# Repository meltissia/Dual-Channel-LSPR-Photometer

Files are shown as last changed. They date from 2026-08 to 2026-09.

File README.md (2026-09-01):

# Dual-Channel LSPR Photometer Platform

Компактна двоканальна фотометрична платформа для реєстрації та цифрової обробки сигналів фотодіодів при дослідженні локалізованого поверхневого плазмонного резонансу (LSPR).

Пристрій побудований на **ESP32-WROOM-32**, 24-бітному ΔΣ АЦП **ADS1220** та двоканальному трансимпедансному analog front-end на **AD8616**.

Поточна апаратна ревізія **Rev.1.0** є Proof of Concept та використовувалася для повного bring-up аналогового, цифрового та програмного вимірювального тракту.

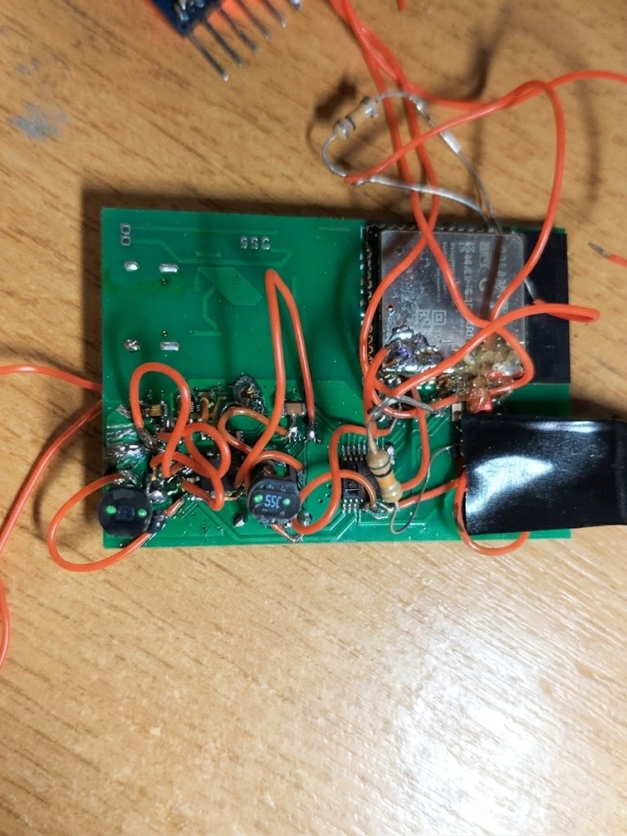
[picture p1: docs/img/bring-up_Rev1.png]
Rev.1 hardware prototype


---

## Hardware Overview

| Вузол | Специфікація |
|---|---|
| **MCU** | ESP32-WROOM-32 |
| **ADC** | ADS1220, 24-bit Delta-Sigma (Internal 2.048 V ref, 20 SPS, single-shot) |
| **Analog Front-End** | Dual AD8616 TIA (`Rf = 5.1 MΩ`, `Cf = 10 pF`), photovoltaic mode |
| **Bias** | `VSHIFT ≈ 1.42 V` relative to GNDA (measured on Rev.1.0) |
| **Sensors** | 2 × Hamamatsu S1087 Silicon Photodiodes |
| **Light Source** | Measurement LED switched via ESP32 GPIO27 |
| **Power** | BQ24074 charger + TPS63031 3.3 V buck-boost (shared digital/analog rail) |
| **PCB** | Custom 2-layer PCB, Rev.1.0 |
| **Status** | **Rev.1.0 PoC verified** — bring-up завершено; сформовано ТЗ на Rev.1.1 |

ADS1220 конфігурується у диференціальному режимі:
- **CH1:** `AIN0 − AIN1` (AIN1 підтягнуто до `VSHIFT`)
- **CH2:** `AIN2 − AIN3` (AIN3 підтягнуто до `VSHIFT`)

Зсув `VSHIFT ≈ 1.42 V` задає робочу common-mode точку для коректного оцифрування двополярного сигналу при однополярному живленні 3.3 В.

---

## System Architecture

```mermaid
flowchart LR
    subgraph OPTICAL ["Optical Front-End"]
        LED["Measurement LED<br/>(GPIO27)"]
        PD1["Hamamatsu S1087<br/>CH1"]
        PD2["Hamamatsu S1087<br/>CH2"]
    end

    subgraph AFE ["Analog Front-End"]
        TIA1["AD8616 TIA CH1<br/>Rf = 5.1 MΩ, Cf = 10 pF"]
        TIA2["AD8616 TIA CH2<br/>Rf = 5.1 MΩ, Cf = 10 pF"]
        VSHIFT["VSHIFT ≈ 1.42 V"]
    end

    subgraph ADC ["Acquisition"]
        ADS["ADS1220 (24-bit ΔΣ)<br/>Internal Ref 2.048 V | 20 SPS"]
    end

    subgraph MCU ["ESP32 Firmware Pipeline"]
        PIPE["• Sample averaging<br/>• Dark correction<br/>• Moving average (N=8)<br/>• Code → µV conversion<br/>• CH1/CH2 ratio"]
        UART["UART0 / CSV Output"]
    end

    LED -.-> PD1
    LED -.-> PD2

    PD1 --> TIA1
    PD2 --> TIA2

    VSHIFT -.-> TIA1
    VSHIFT -.-> TIA2

    TIA1 --> ADS
    TIA2 --> ADS

    ADS -- "SPI + DRDY" --> PIPE
    PIPE --> UART
```

---

## Firmware Overview

Прошивка реалізована мовою C під **ESP-IDF v6.0.2** для target `esp32`.

- **`ads1220`** — низькорівневий драйвер: конфігурація регістрів (`WREG`/`RREG`), контроль `DRDY`, таймінги передачі та читання 24-бітних вибірок.
- **`photometer`** — вимірювальний шар: мультиплексування каналів, віднімання темного струму (dark correction), усереднення, рухоме середнє ($N=8$) та розрахунок коефіцієнта каналів.
- **`photometer_output`** — пакетування та потоковий вивід даних у UART.
- **`main`** — секвенсер калібрування, керування оптичним джерелом та запуск циклу вимірювань.

---

## Quick Start

### Build & Flash

```bash
# Встановлення цільового чіпа та збірка
idf.py set-target esp32
idf.py build

# Прошивка та монітор (Windows: COMx, Linux/macOS: /dev/ttyUSBx)
idf.py -p COM7 flash monitor
```

*Примітка:* Розпіновка SPI та системних інтерфейсів зафіксована у коді Rev.1.0; деталі наведено у [Hardware Architecture & Pinout](docs/hardware.md).

---

## Data Output

Вимірювання транслюються через `UART0` у CSV-подібному форматі:

```text
DATA,40004171,26,1043353,1031889,11464,2798.828,11595,2830.811,204278,682426,-478148,-116735.352,-473754,-115662.598,-0.023976,-0.024475,1,1,0,0
```

Кожен рядок фіксує сирі коди обох каналів, значення темного зміщення, скориговані сигнали в $\mu\text{V}$, результат фільтрації, обчислене співвідношення та статус-прапорці saturation/validity.

Повний лог першого запуску:[**rev1_ads1220_.bringup_log.csv**](docs/logs/rev1_ads1220_.bringup_log.csv)

Структура полів та опис даних: [**Data Format & Bring-up Logs**](docs/logs/README.md)

> Дані першого запуску демонструють стабільну роботу цифрового SPI-тракту після усунення апаратних збоїв шини і не є метрологічно каліброваними.

---

## Limitations & Rev.1.1 Requirements

На ревізії Rev.1.0 зафіксовано апаратні обмеження, що увійшли до плану модернізації:

1. **Шум живлення:** Спільна шина 3.3 В від імпульсного перетворювача TPS63031 безпосередньо впливає на аналоговий тракт. Для Rev.1.1 закладено виділений ultra-low-noise LDO.
2. **Топологія AFE:** Відсутність виділеного guard ring навколо високоомного кола фотодіодів ($R_f = 5.1\,\text{M}\Omega$).
3. **Debug & Programming:** Відсутність розведеного окремого роз'єму для UART/EN/BOOT на платі.
4. **Метрологія:** Довготривалий дрейф, SNR, лінійність та повторюваність вимірювань перенесені на стендове тестування ревізії Rev.1.1.

---

## Documentation

- **Hardware:** [Hardware Architecture & Pinout](docs/hardware.md) · [PCB Design & Manufacturing Files](docs/hardware/) · [Hardware Errata](docs/ERRATA.md)
- **Firmware:** [Firmware Implementation & Notes](docs/firmware.md) · [Firmware Errata](docs/FIRMWARE_ERRATA.md)
- **Experimental Data:** [Data Format & Bring-up Logs](docs/logs/README.md)

---

## Legacy

Архітектура приладу розвиває концепцію двоканального LSPR-фотометра на базі **ATtiny2313(A)** та **ADS1242** (Assembly), реалізуючи аналогічний диференціальний оптичний принцип на сучасному 32-бітному ядрі ESP32.

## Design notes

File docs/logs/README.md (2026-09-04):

# UART Bring-up Logs

Референсний набір даних: [`rev1_ads1220_.bringup_log.csv`](rev1_ads1220_bringup_log.csv).

Цей набір даних збережено як підтвердження роботи цифрового acquisition pipeline Rev.1.0 після стабілізації SPI-інтерфейсу. Він містить двоканальне зчитування ADC, dark correction, перерахунок ADC-коду, moving-average processing, розрахунок співвідношення каналів та структурований UART output.

На стабільних ділянках логу відсутні раніше зафіксовані структуровані пошкодження SPI-даних, зсуви байтів та великі стрибки до некоректних ADC-кодів.

Зафіксовані фізичні значення сигналів не є метрологічно валідованими та не повинні інтерпретуватися як характеристика точності фотометра, noise floor, чутливості або довготривалої стабільності.

---

## Схема CSV Output

```text
record_type, timestamp_us, measurement_number,
ch1_raw, ch1_dark, ch1_corrected, ch1_uv, ch1_filtered, ch1_filtered_uv,
ch2_raw, ch2_dark, ch2_corrected, ch2_uv, ch2_filtered, ch2_filtered_uv,
ratio, filtered_ratio, ratio_valid, filtered_ratio_valid, ch1_saturated, ch2_saturated
```

### Приклад рядка

```text
DATA,40004171,26,1043353,1031889,11464,2798.828,11595,2830.811,204278,682426,-478148,-116735.352,-473754,-115662.598,-0.023976,-0.024475,1,1,0,0
```

> **Примітка:** Значення є даними bring-up та не являють собою абсолютну метрологічну калібровку.

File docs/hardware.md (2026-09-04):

# Апаратна архітектура та Errata (Rev.1.0)

## Аналоговий Front-End та Pinout

- **TIA:** AD8616 dual op-amp (`Rf = 5.1 MΩ`, `Cf = 10 pF`), photovoltaic mode.

- **Bias:** `VSHIFT ≈ 1.42 V` відносно GNDA для псевдодиференціального двополярного розмаху сигналу при однополярному живленні 3.3 V.

- **Сенсори:** 2 × фотодіоди Hamamatsu S1087.

- **Живлення:** BQ24074 charger + TPS63031 buck-boost зі спільною цифровою та аналоговою шиною живлення.

### Pin Mapping

| Периферія | Сигнал | ESP32 GPIO | Напрямок |
|---|---|---:|---|
| ADS1220 | CS | GPIO5 | Output |
| ADS1220 | DRDY | GPIO16 | Input |
| ADS1220 | SCLK | GPIO18 | Output |
| ADS1220 | DOUT | GPIO19 | Input |
| ADS1220 | DIN | GPIO23 | Output |
| Control | LED Trigger | GPIO27 | Output |
| Debug | UART0 TX / RX | GPIO1 / GPIO3 | — |

---

## Відомі проблеми та вимоги до Rev.1.1

- **Шина живлення:** Аналоговий front-end та ADC у Rev.1.0 живляться безпосередньо від спільної шини 3.3 V, сформованої TPS63031, без окремого low-noise post-regulation stage. Через це switching ripple та цифрові завади шини живлення потенційно можуть проникати у прецизійний аналоговий тракт.  
  *Rev.1.1:* Додати окреме малошумне живлення аналогового домену із застосуванням LDO або відповідного post-regulation / filtering stage з достатнім запасом напруги.

- **Guard Ring:** У Rev.1.0 guard structure була прив'язана до `GNDA` замість потенціалу `VSHIFT`, відносно якого працює високоімпедансний вузол TIA.  
  *Rev.1.1:* Перерозвести guard навколо високоімпедансних вузлів фотодіода/TIA та прив'язати його до `VSHIFT`, враховуючи паразитну ємність під час PCB layout.

- **Debug:** У Rev.1.0 не було передбачено окремого UART programming/debug header або JTAG access header.

- **Метрологія:** Довготривалий аналоговий дрейф, SNR та оптична лінійність мають бути валідовані на Rev.1.1.

## Рендери PCB Layout

<figure>
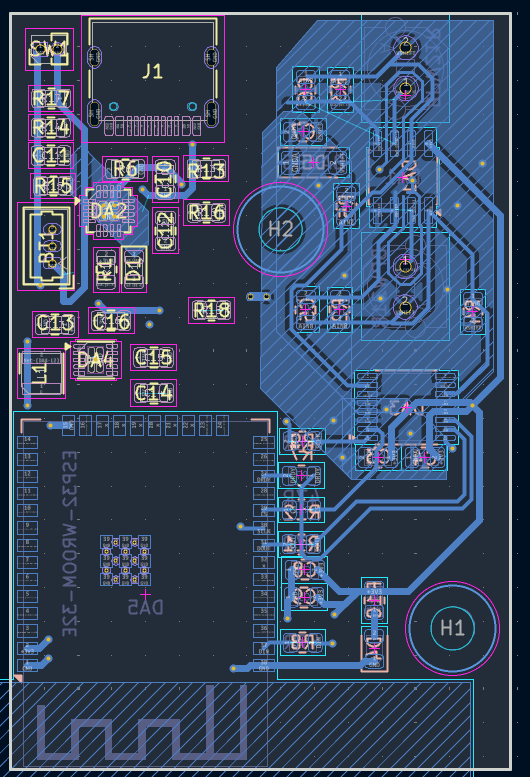
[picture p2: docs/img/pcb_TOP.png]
PCB Top Layer
  
  <figcaption align="center"><em>Рисунок 1 — Трасування верхнього шару (Top Layer): аналоговий тракт TIA, АЦП та обв'язка ESP32</em></figcaption>
</figure>

<figure>
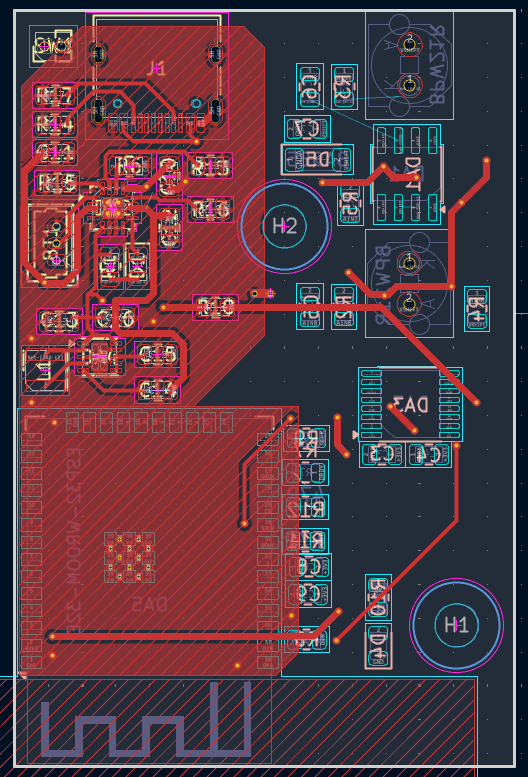
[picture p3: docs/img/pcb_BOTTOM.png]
PCB Bottom Layer
  
  <figcaption align="center"><em>Рисунок 2 — Трасування нижнього шару (Bottom Layer): суцільний полігон землі (GND plane) та силові ланцюги</em></figcaption>
</figure>

<figure>
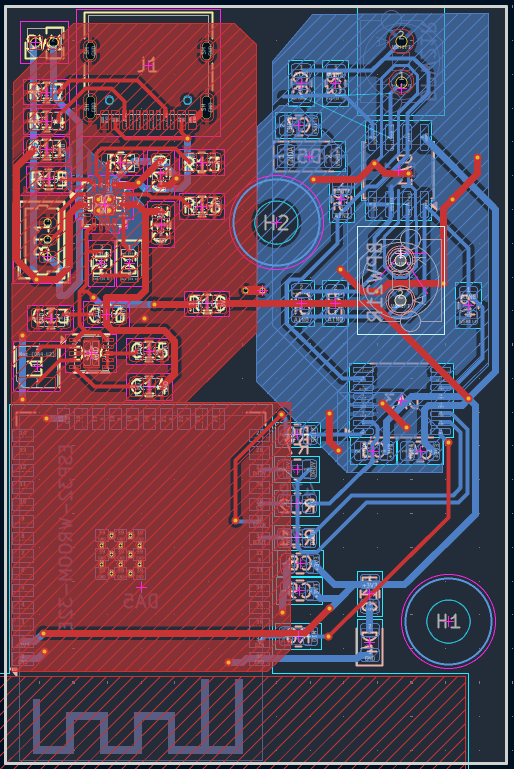
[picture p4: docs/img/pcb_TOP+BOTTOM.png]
PCB Top and Bottom Layers
  
  <figcaption align="center"><em>Рисунок 3 — Комбінований вигляд шарів (Top + Bottom): взаємне розташування трас і перехідних отворів</em></figcaption>
</figure>

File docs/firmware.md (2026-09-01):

# Реалізація прошивки та нотатки Bring-up

Зібрано з використанням **ESP-IDF v6.0.2** для target `esp32`.

## Структура модулів

- `ads1220.c / .h`: Низькорівневий драйвер, конфігурація регістрів через `WREG` / `RREG` із read-back перевіркою, обробка timeout для `DRDY`, запуск перетворень та перерахунок сирого ADC-коду у µV.

- `photometer.c / .h`: Двоканальне мультиплексоване зчитування, калібрування та корекція dark offset, boxcar moving average (`N = 8`), перевірка saturation та розрахунок співвідношення каналів.

- `photometer_output.c / .h`: Формування структурованого CSV-потоку через UART із timestamp та status flags.

- `main.c`: Керування апаратним bring-up та безперервним циклом збору даних.

## Нотатки Bring-up та Workaround

- Під час bring-up Rev.1.0 апаратний SPI-зв'язок з ADS1220 залишався нестабільним навіть при знижених тактових частотах. Тому драйвер було переведено на GPIO bit-bang SPI з явним програмним керуванням таймінгами `CS`, `SCLK`, `DIN` та `DOUT`.

- Для надійного доступу до регістрів та читання 24-бітних результатів перетворення знадобилися консервативні часові інтервали між змінами станів цифрових ліній.

- Перед читанням результату перетворення стан `DRDY` опитується з timeout, що запобігає необмеженому блокуванню та читанню даних до завершення ADC conversion.

- На Rev.1.0 додатково знадобилася повторна валідація `RDATA`, оскільки окремі 24-бітні читання могли залишатися пошкодженими навіть при коректному стані `DRDY`.

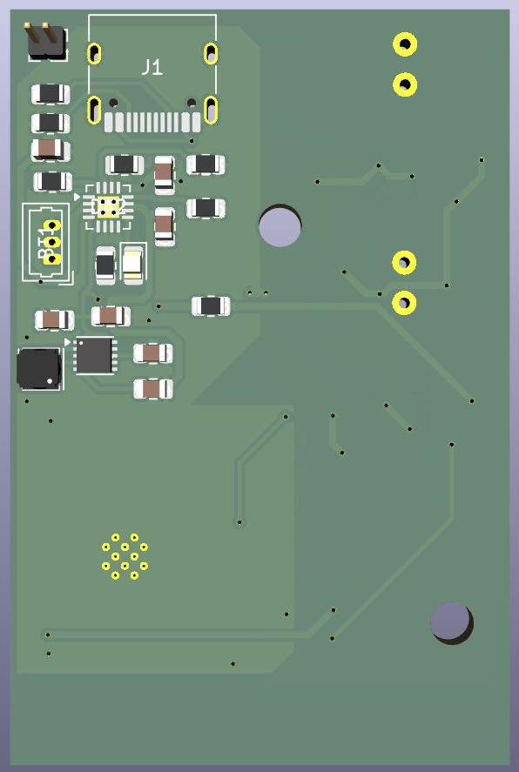
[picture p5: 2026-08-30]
docs/img/pcb_3D_BOTTOM.png

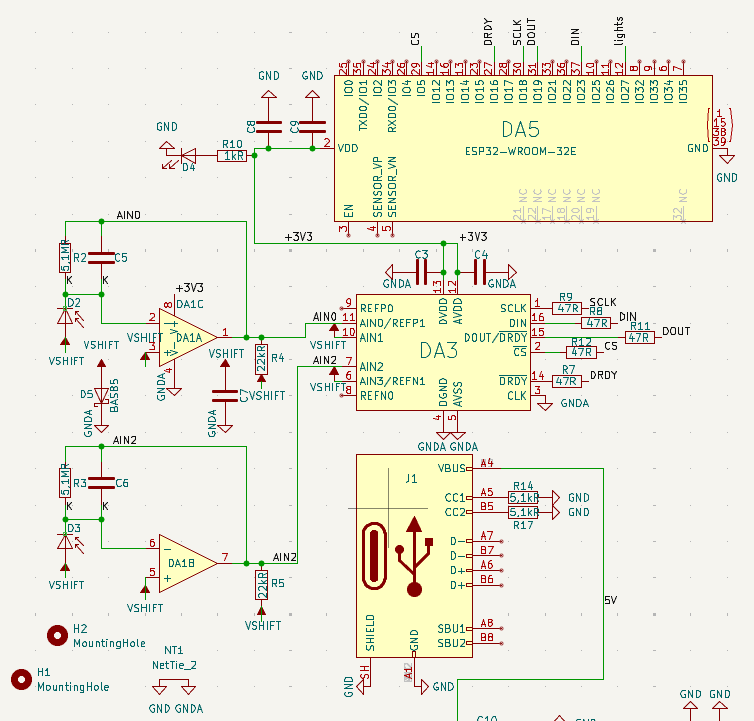
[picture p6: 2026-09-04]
docs/img/scheme_ANALOG.png

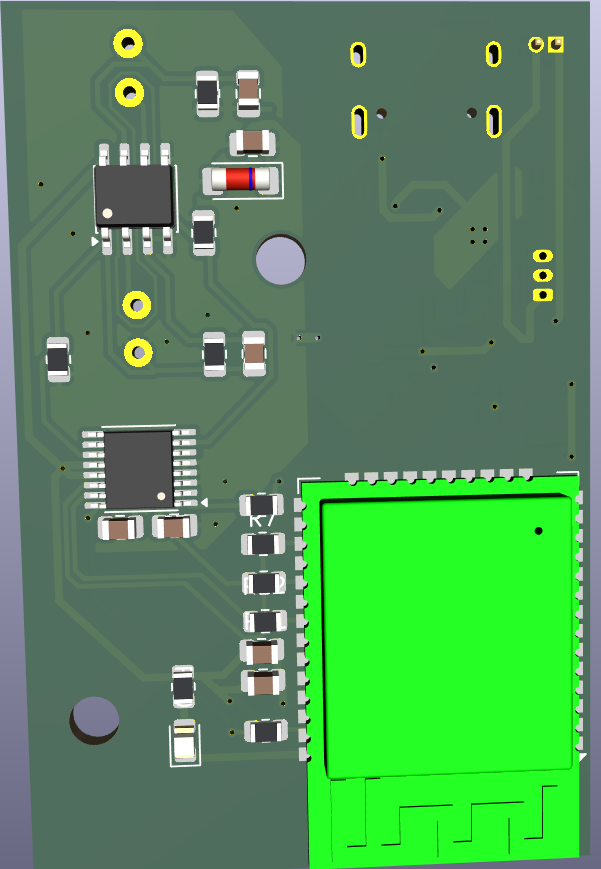
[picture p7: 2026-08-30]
docs/img/pcb_3D_TOP.png

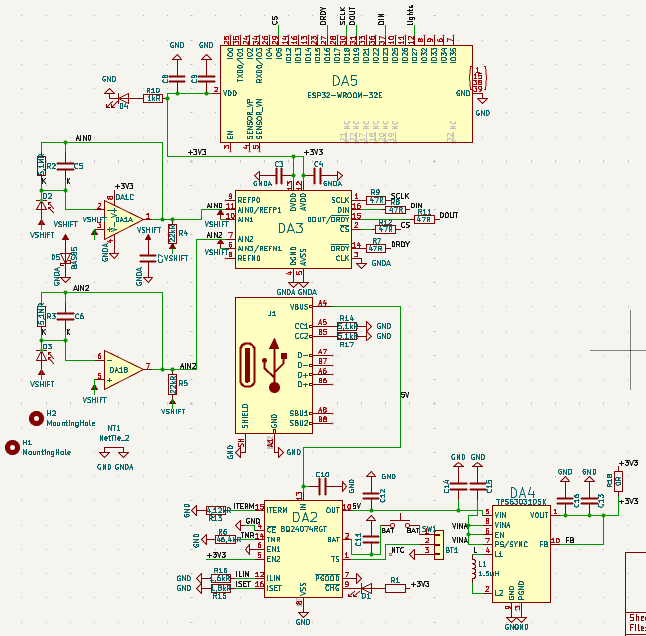
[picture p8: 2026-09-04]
docs/img/scheme_ALL.png

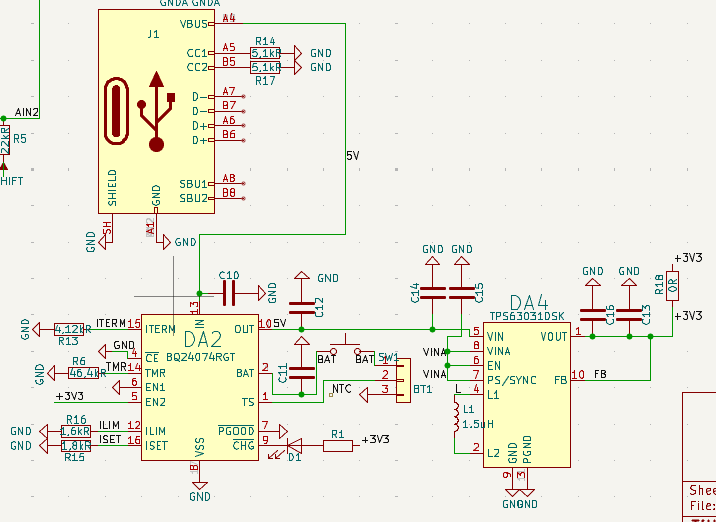
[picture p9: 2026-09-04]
docs/img/scheme.POWER.png

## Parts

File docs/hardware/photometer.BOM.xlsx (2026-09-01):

Reference | Qty | Value | DNP | Exclude from BOM | Exclude from Board | Footprint | Datasheet
BT1 | 1 | Akyga LP603450 PCM+NTC |  |  |  | Connector_Molex:Molex_PicoBlade_53047-0310_1x03_P1.25mm_Vertical
C3,C4,C8,C15 | 3 | 100nF |  |  |  | Capacitor_SMD:C_0805_2012Metric
C5,C6 | 2 | 10nF |  |  |  | Capacitor_SMD:C_0805_2012Metric
C7 | 1 | 220nF |  |  |  | Capacitor_SMD:C_0805_2012Metric
C9,C10,C13,C14,C16 | 5 | 10mcF |  |  |  | Capacitor_SMD:C_0805_2012Metric
C11,C12 | 2 | 4,7mcF |  |  |  | Capacitor_SMD:C_0805_2012Metric
D1 | 1 | LED Red, 0805 |  |  |  | LED_SMD:LED_0805_2012Metric
D2,D3 | 2 | BPW21R |  |  |  | Diode_THT:Hamamatsu_S1087_THT2
D4 | 1 | LED Green, 0805 |  |  |  | LED_SMD:LED_0805_2012Metric
D5 | 1 | BAS85 |  |  |  | Diode_SMD:D_MiniMELF
DA1 | 1 | AD8616ARZ |  |  |  | Package_SO:SOIC-8_3.9x4.9mm_P1.27mm
DA2 | 1 | BQ24074RGT |  |  |  | Package_DFN_QFN:VQFN-16-1EP_3x3mm_P0.5mm_EP1.6x1.6mm | http://www.ti.com/lit/ds/symlink/bq24074.pdf
DA3 | 1 | ADS1220xPW |  |  |  | Package_SO:TSSOP-16_4.4x5mm_P0.65mm | http://www.ti.com/lit/ds/symlink/ads1220.pdf
DA4 | 1 | TPS63031DSK |  |  |  | Package_SON:WSON-10-1EP_2.5x2.5mm_P0.5mm_EP1.2x2mm | http://www.ti.com/lit/ds/symlink/tps63031.pdf
DA5 | 1 | ESP32-WROOM-32E |  |  |  | RF_Module:ESP32-WROOM-32E | https://www.espressif.com/sites/default/files/documentation/esp32-wroom-32e_esp32-wroom-32ue_datasheet_en.pdf
J1 | 1 | USB_C_Receptacle_USB2.0_16P |  |  |  | Connector_USB:USB_C_Receptacle_HRO_TYPE-C-31-M-12 | https://www.usb.org/sites/default/files/documents/usb_type-c.zip
L1 | 1 | 1.5uH |  |  |  | Inductor_SMD_Wurth:L_Wurth_WE-LQSH-3012
R1,R10 | 2 | 1kR |  |  |  | Resistor_SMD:R_0805_2012Metric
R2,R3 | 2 | 5,1MR |  |  |  | Resistor_SMD:R_0805_2012Metric
R4,R5 | 2 | 22kR |  |  |  | Resistor_SMD:R_0805_2012Metric
R6 | 1 | 620kR |  |  |  | Resistor_SMD:R_0805_2012Metric
R7,R8,R9,R11,R12 | 5 | 47R |  |  |  | Resistor_SMD:R_0805_2012Metric
R13 | 1 | 4.3kR |  |  |  | Resistor_SMD:R_0805_2012Metric
R14,R17 | 2 | 5,1kR |  |  |  | Resistor_SMD:R_0805_2012Metric
R15 | 1 | 1,8kR |  |  |  | Resistor_SMD:R_0805_2012Metric
R16 | 1 | 1,6kR |  |  |  | Resistor_SMD:R_0805_2012Metric
R18 | 1 | 0R |  |  |  | Resistor_SMD:R_0805_2012Metric

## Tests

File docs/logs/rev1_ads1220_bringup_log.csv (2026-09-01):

record_type | timestamp_us | measurement_number | ch1_raw | ch1_dark | ch1_corrected | ch1_uv | ch1_filtered | ch1_filtered_uv | ch2_raw | ch2_dark | ch2_corrected | ch2_uv | ch2_filtered | ch2_filtered_uv | ratio | filtered_ratio | ratio_valid | filtered_ratio_valid | ch1_saturated | ch2_saturated
DATA | 1504235 | 1 | 962262 | 911858 | 50404 | 12305.664 | 50404 | 12305.664 | 313635 | 297193 | 16442 | 4014.160 | 16442 | 4014.160 | 3.065564 | 3.065564 | 1 | 1 | 0 | 0
DATA | 3044171 | 2 | 1011614 | 994121 | 17493 | 4270.752 | 33948 | 8288.086 | 313538 | 319199 | -5661 | -1382.080 | 5390 | 1315.918 | -3.090090 | 6.298330 | 1 | 1 | 0 | 0
DATA | 4584171 | 3 | 1022165 | 1015368 | 6797 | 1659.424 | 24898 | 6078.613 | 312594 | 319781 | -7187 | -1754.639 | 1198 | 292.480 | -0.945735 | 20.782972 | 1 | 1 | 0 | 0
DATA | 6124171 | 4 | 1027233 | 1020924 | 6309 | 1540.283 | 20250 | 4943.848 | 313350 | 317090 | -3740 | -913.086 | -36 | -8.789 | -1.686898 | -562.500000 | 1 | 1 | 0 | 0
DATA | 7664171 | 5 | 1029784 | 1025422 | 4362 | 1064.941 | 17073 | 4168.213 | 329980 | 317011 | 12969 | 3166.260 | 2564 | 625.977 | 0.336341 | 6.658736 | 1 | 1 | 0 | 0
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

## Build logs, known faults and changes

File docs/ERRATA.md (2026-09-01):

# Hardware Errata & Bring-up Log (Rev.1.0)

Документація апаратних проблем ревізії Rev.1.0, тимчасових доробок Bring-up та вимог до редизайну принципової схеми й топології друкованої плати Rev.1.1.

---

## 1. Апаратна частина (Hardware Errata & Fixes)

### Аналоговий тракт (TIA, Guard Ring & Bias)

- **Помилка топології TIA та фотодіодного вузла у принциповій схемі:**
  - *Проблема:* Аналоговий вузол Rev.1.0 був спроєктований некоректно на рівні принципової схеми. Вихід ОУ/вхід АЦП був помилково пов'язаний з `VSHIFT`, а підключення фотодіода та ланцюга зворотного зв'язку не відповідали правильній топології TIA.
  - *Root cause:* Помилка на етапі розробки принципової схеми Rev.1.0. Некоректна електрична топологія була перенесена в PCB layout без виявлення помилки до виготовлення плати.
  - *Rev.1 Fix:* Неправильні з'єднання фізично розірвані перерізанням доріжок і видаленням зайвих ділянок міді. Необхідні з'єднання TIA та фотодіодного вузла відновлено навісним монтажем і перемичками МГТФ. Ланцюг зворотного зв'язку (`R∥C`) залишено між виходом та інвертуючим входом ОУ; `VSHIFT` заведено на неінвертуючий вхід та анод фотодіода.
  - *Rev.1.1:* Повністю виправити принципову схему TIA і фотодіодного вузла, після чого заново виконати трасування аналогової частини. Перед переходом до PCB провести окрему перевірку netlist, полярності фотодіода та топології зворотного зв'язку.

- **Розрив полігону/траси VSHIFT:**
  - *Проблема:* Мережа `VSHIFT` виявилася фізично розірваною на дві незв'язані частини.
  - *Rev.1 Fix:* З'єднано перемичкою МГТФ з наскрізним продзвонюванням.
  - *Rev.1.1:* Відновити цілісність мережі `VSHIFT` та перевірити connectivity перед генерацією Gerber.

- **Топологія Guard Ring:**
  - *Проблема:* Охоронний провідник був підключений до `GNDA`, тоді як високоімпедансний вузол TIA працює поблизу потенціалу `VSHIFT`. Різниця потенціалів між сигнальним вузлом і guard-провідником збільшує вплив поверхневих струмів витоку через PCB.
  - *Rev.1.1:* Перерозвести guard-провідник навколо високоімпедансного вузла та підключити його до потенціалу `VSHIFT`. Використання суцільної захисної заливки під вузлом оцінювати окремо з урахуванням додаткової паразитної ємності.

#### Схема перекройки аналогового вузла TIA та Guard Ring:

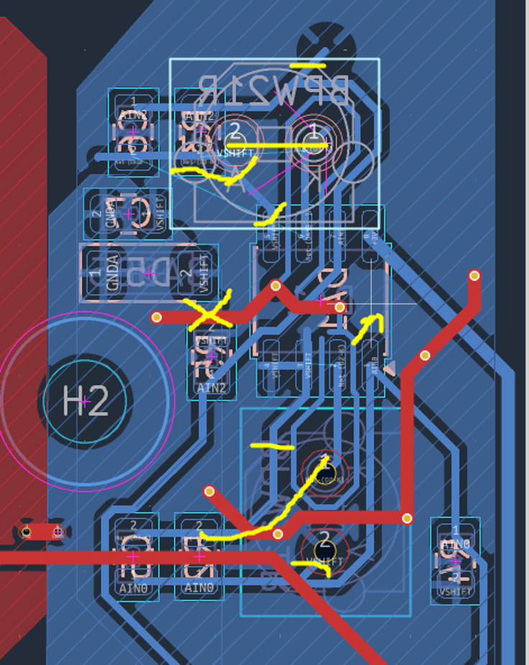
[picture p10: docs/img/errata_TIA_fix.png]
Схема виправлень вузла TIA


---

### Трасування АЦП, Зазори та Компонування

- **Недостатні технологічні зазори навколо ADS1220 (TSSOP-16):**
  - *Проблема:* Траси `DIN`, `DOUT`, `SCLK`, `DRDY` та `3V3` розведені занадто близько до виводів ADS1220, що ускладнює ручний монтаж, діагностику та локальний rework і підвищує ризик утворення паяльних містків та механічного пошкодження виводів.
  - *Rev.1.1:*
    - Збільшити clearance навколо ADS1220.
    - Спростити доступ до цифрових сигнальних ліній та, за можливості, передбачити test points для діагностики.
    - Фізично рознести цифрові SPI-лінії (`SCLK`, `DIN`, `DOUT`, `DRDY`) та чутливі аналогові входи ADS1220.
    - Уникати тривалого паралельного трасування цифрових і аналогових ліній.
    - Мінімізувати площу високочутливих аналогових вузлів.

- **Тісне компонування компонентів:**
  - *Проблема:* Резистори 47 Ом змонтовані впритул до модуля ESP32; роз'єм Molex акумулятора перекриває доступ до BQ24074.
  - *Rev.1.1:* Збільшити габарити плати орієнтовно в 1.5 раза для нормального доступу до вимірювальних вузлів, діагностики та ручного монтажу.

- **Помилка підключення R6:**
  - *Проблема:* Відсутній зв'язок одного з падів R6 із землею.
  - *Rev.1 Fix:* З'єднання з GND відновлено перемичкою.
  - *Rev.1.1:* Додати штатне via або пряме з'єднання з GND.

- **Помилка підключення C14:**
  - *Проблема:* До GND-паду C14 через термобар'єр було помилково підведено `5V`, що створювало пряме КЗ `5V ↔ GND`.
  - *Rev.1 Fix:* Хибну трасу `5V` відсічено.
  - *Rev.1.1:* Прибрати помилкову доріжку та повторно перевірити net connectivity вузла.

---

### Відсутність окремого малошумного живлення аналогового тракту

- **Проблема:** У Rev.1.0 аналоговий front-end та ADC живляться безпосередньо від системної шини `3.3 V`, сформованої імпульсним buck-boost перетворювачем TPS63031. Окремий low-noise post-regulation stage для прецизійного аналогового тракту не передбачений.

- **Наслідок:** Switching ripple та високочастотні завади системної шини потенційно можуть проникати у TIA, ADC та bias/reference nodes і погіршувати noise floor вимірювального тракту.

- **Rev.1.1:** Передбачити окреме малошумне живлення аналогового домену. Розглянути low-noise LDO з достатнім dropout/headroom або окремий post-regulation/filtering stage. Остаточну топологію та напругу аналогової шини визначити після розрахунку power budget, PSRR та допустимих діапазонів живлення AFE/ADC.

---

### Цифровий вузол та інтерфейс програмування

- **Інтерфейс прошивки та Reset/Boot-ланцюги ESP32:**
  - *Проблема:* Відсутність контактних майданчиків для `EN`, `GPIO0`, `TX0`, `RX0` ускладнила прошивання, перехід у Bootloader та діагностику плати. Під час bring-up довелося встановлювати зовнішні pull-up резистори навісним монтажем.
  - *Rev.1.1:*
    - Додати штатний UART/debug-роз'єм (`GND`, `TXD`, `RXD`, `EN`, `GPIO0`).
    - Встановити зовнішні pull-up/RC-елементи для `EN` і `GPIO0` відповідно до рекомендованої схеми ESP32-WROOM та обраної схеми auto-reset.

---

### Оптичне компонування та паразитна засвітка

- **Паразитний вплив статусного LED на вимірювальний тракт:**
  - *Проблема:* Червоний статусний LED розташований поблизу фотодіодів Hamamatsu S1087. Спектральний діапазон S1087 охоплює червону область, тому випромінювання індикатора може безпосередньо реєструватися вимірювальними каналами як паразитний оптичний сигнал.
  - *Додатковий фактор:* Локальний нагрів LED і прилеглої області PCB потенційно може створювати температурний дрейф фотодіодів та аналогового тракту.
  - *Rev.1 Fix:* LED екранується непрозорим матеріалом та, за можливості, вимикається під час критичних вимірювань.
  - *Rev.1.1:*
    - Передбачити механічне світлоблокування між індикаторними LED, фотодіодами та оптичним каналом для запобігання прямій і відбитій паразитній засвітці.
    - Збільшити оптичну та теплову розв'язку між індикаторними LED та фотодіодами.
    - Передбачити програмне вимкнення індикаторних LED на час вимірювального циклу.
    - Остаточне розташування LED визначити після експериментальної перевірки паразитної засвітки та температурного впливу.
    - Експериментально визначити необхідну затримку між вимкненням LED та початком прецизійного вимірювання.

---

## 2. Програмні воркараунди (Firmware Workarounds)

*Тимчасові модифікації коду, внесені під час bring-up Rev.1.0:*

- **Програмний Pull-up для сигнальних ліній:**
  - Конфігурація внутрішніх підтяжок `GPIO_PULLUP` в ESP-IDF використовувалася для компенсації відсутності зовнішніх резисторів на окремих цифрових лініях Rev.1.0.

- **Додаткові затримки під час ініціалізації ADS1220:**
  - Під час діагностики Rev.1.0 використовувалися збільшені програмні затримки перед доступом до SPI-регістрів ADS1220.
  - Конкретний апаратний механізм, який вимагав цих затримок, не встановлений.
  - Не вважати ці затримки постійним апаратним workaround до повторної перевірки їх необхідності після виготовлення Rev.1.1.

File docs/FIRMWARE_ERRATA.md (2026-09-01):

# Firmware Errata & Bring-up Notes (Rev.1.0)

Документація проблем програмного забезпечення, виявлених під час bring-up апаратної ревізії Rev.1.0, тимчасових firmware workaround та вимог до повторної перевірки після переходу на Rev.1.1.

---

## 1. Інтерфейс ADS1220 та SPI

### Нестабільна робота ADS1220 через апаратний SPI ESP32

- **Проблема:** Під час bring-up не вдалося отримати стабільний обмін з ADS1220 через апаратний SPI-контролер ESP32. Зниження частоти SPI, включно приблизно до 100 кГц, не усунуло нестабільність.
- **Прояв:** Періодичні помилки читання/запису регістрів ADS1220 та некоректні результати перетворення.
- **Root cause:** Остаточно не встановлений. Під час bring-up одночасно існували апаратні дефекти та нестабільність фізичних сигнальних ліній Rev.1.0, тому неможливо однозначно віднести проблему до SPI-периферії ESP32 або PCB.
- **Rev.1 Workaround:** Апаратний SPI замінено програмною реалізацією SPI через GPIO (bit-bang), з повним ручним керуванням `CS`, `SCLK`, `DIN` та читанням `DOUT`.
- **Rev.1.1:** Після усунення апаратних дефектів PCB повторно перевірити роботу штатного hardware SPI. Bit-bang не вважати обов'язковою архітектурою наступної ревізії без повторної валідації.

---

### Недостатні часові інтервали у початковій реалізації bit-bang SPI

- **Проблема:** Початкова реалізація програмного SPI використовувала затримки близько `10 µs` між змінами станів GPIO. За таких таймінгів інтерфейс періодично повертав пошкоджені дані.
- **Прояв:** Під час `RDATA` спостерігалися структуровані помилкові 24-бітні значення, великі стрибки коду та невідповідність між повторними читаннями однієї конверсії.
- **Rev.1 Workaround:** Затримки всередині передачі одного біта збільшено. Стабільна робота підтверджена при `50 µs`, після чого перевірено та залишено `30 µs`.
- **Rev.1.1:** Повторно визначити необхідні SPI timing після виправлення PCB. Значення `30 µs` розглядати як консервативний workaround Rev.1.0, а не як вимогу ADS1220.

---

### Чутливість до моменту вибірки DOUT відносно SCLK

- **Проблема:** Під час діагностики перевірялася альтернативна вибірка `DOUT` при високому рівні `SCLK`.
- **Прояв:** Зміна моменту вибірки призводила до негайної нестабільності `RREG` та неправильного читання регістрів.
- **Rev.1 Fix:** У робочій реалізації стан `DOUT` зчитується після спаду `SCLK`.
- **Rev.1.1:** Не змінювати фазу вибірки без повторної перевірки відповідно до timing diagram ADS1220 та вимірювання реальних фронтів сигналів.

---

### Відсутність достатньої перевірки конфігурації ADS1220 після запису регістрів

- **Проблема:** Одного виконання `WREG` недостатньо для підтвердження успішної конфігурації АЦП при нестабільному цифровому інтерфейсі.
- **Прояв:** Запис регістра міг завершитися без програмної помилки, але подальше читання показувало інше значення.
- **Rev.1 Fix:** Після конфігурації виконується `RREG` кожного конфігураційного регістра та порівняння з очікуваним значенням. При mismatch ініціалізація завершується помилкою.
- **Rev.1.1:** Зберегти read-back verification як механізм діагностики та контролю цілісності конфігурації.

---

### Необмежене очікування DRDY

- **Проблема:** Очікування завершення перетворення ADS1220 не повинно блокувати firmware необмежений час у випадку втрати `DRDY`, помилки SPI або несправності АЦП.
- **Rev.1 Fix:** Після `START/SYNC` реалізовано очікування готовності `DRDY` з програмним timeout.
- **Результат:** При відсутності готовності АЦП функція завершується контрольованою помилкою замість зависання вимірювального циклу.
- **Rev.1.1:** Зберегти timeout та обробку помилок як штатну частину драйвера.

---

### Недостатня надійність одиночного RDATA на Rev.1.0

- **Проблема:** Під час bring-up одиночна транзакція `RDATA` іноді повертала пошкоджений 24-бітний результат навіть після переходу `DRDY` у стан готовності.
- **Діагностика:** Повторне читання тієї самої конверсії показало, що перше значення могло відрізнятися, тоді як наступні читання повертали однаковий код.
- **Rev.1 Workaround:** Реалізовано до декількох незалежних транзакцій `RDATA`. Результат приймається лише після отримання двох послідовних повністю однакових 24-бітних значень.
- **Помилка:** Якщо стабільна пара значень не отримана за встановлену кількість спроб, повертається `ESP_ERR_INVALID_RESPONSE`.
- **Rev.1.1:** Після виправлення апаратного SPI-тракту перевірити необхідність цього workaround. За стабільного інтерфейсу перейти до штатного одиночного читання конверсії або залишити повторне читання лише як діагностичний механізм.

---

### Недетерміноване керування межами SPI-транзакцій у початковій реалізації

- **Проблема:** Під час раннього bring-up стан `SCLK` та межі окремих SPI-транзакцій не забезпечували достатньо передбачуваної поведінки протягом повного циклу запису/читання ADS1220.
- **Rev.1 Workaround:** У bit-bang реалізації програмне забезпечення явно формує кожну транзакцію:
  - `CS = LOW`;
  - передача команди;
  - передача або читання необхідних байтів;
  - `CS = HIGH`.
- **Додатково:** Рівень `SCLK` формується виключно програмно під час передачі кожного біта.
- **Rev.1.1:** При поверненні до hardware SPI повторно перевірити polarity, phase, idle state `SCLK` та поведінку `CS` між окремими командами ADS1220.

---

## 2. Діагностика та обробка помилок

### Некоректна діагностика стану CS у режимі output-only

- **Проблема:** Під час діагностики використовувалося програмне читання GPIO `CS`, однак пін був сконфігурований лише як вихід, що робило таку перевірку недостатньо надійною для діагностичних цілей.
- **Rev.1 Fix:** `CS` тимчасово переведено в режим `GPIO_MODE_INPUT_OUTPUT`, що дозволило контролювати фактичний логічний стан GPIO програмно.
- **Rev.1.1:** Якщо read-back `CS` не використовується у штатній firmware, повернути пін до мінімально необхідної конфігурації; діагностичний режим залишити опціональним.

---

### Надмірний діагностичний printf у часово-критичних циклах

- **Проблема:** Велика кількість `printf()` під час SPI stress-test та RDATA-діагностики істотно збільшувала навантаження на UART та scheduler.
- **Прояв:** Спотворений консольний вивід, значні затримки та у окремих тестових конфігураціях watchdog/reset.
- **Rev.1 Fix:** Детальний byte-level logging прибрано з робочого драйвера; у штатному вимірювальному циклі залишено лише необхідний результат та повідомлення про помилки.
- **Rev.1.1:** Розділити production logging і verbose debug logging через compile-time або runtime рівні логування.

---

## 3. Вимірювальний цикл

### Експериментальний лог Rev.1.0

Приклад реального вимірювального циклу, отриманого під час bring-up
з ADS1220, збережено окремо:

[`logs/rev1_ads1220_bringup_log.csv`](logs/rev1_ads1220_bringup_log.csv)

Лог містить raw ADC data, dark correction, перерахунок у µV,
moving average (`N = 8`) та розрахунок співвідношення каналів.

Лог використовується як підтвердження роботи програмного
вимірювального тракту та стабільної передачі 24-бітних даних
після налагодження SPI. Фізичні значення сигналів у цьому наборі
даних не є метрологічно валідованими.

### Невдала стратегія повторної dark calibration перед кожним вимірюванням

- **Проблема:** Було протестовано цикл:
  `LED OFF -> dark calibration -> LED ON -> measurement`
  для кожного окремого вимірювання.
- **Прояв:** На Rev.1.0 така стратегія створювала значні перехідні зміни baseline, особливо на другому каналі, та погіршувала стабільність результату.
- **Root cause:** Точний механізм не встановлений. Поведінка сумісна з повільним встановленням аналогового тракту та накопиченням перехідних процесів.
- **Rev.1 Workaround:** Dark calibration виконується один раз перед серією вимірювань, після чого використовується фіксований dark offset.
- **Rev.1.1:** Після виправлення та повторної характеристики аналогового тракту експериментально визначити оптимальну стратегію dark calibration та необхідний settling time.

---

### Висока нестабільність ratio при малому сигналі другого каналу

- **Проблема:** `channel_ratio` обчислюється діленням сигналу CH1 на CH2. При малому абсолютному значенні CH2 навіть невеликий шум сильно змінює результат ratio.
- **Поточна перевірка:** Валідність ratio блокується лише при точному `CH2 == 0` та saturation.
- **Наслідок:** При значенні CH2, близькому до нуля, ratio формально залишається valid, але може набувати дуже великих і фізично малокорисних значень.
- **Rev.1 Workaround:** Для зменшення шуму введено фільтрацію каналів перед розрахунком `filtered_ratio`.
- **Rev.1.1:** Додати мінімально допустимий поріг `abs(CH2)` для validity ratio замість перевірки лише на точний нуль.

---

### Відсутність цифрової фільтрації у початковому вимірювальному тракті

- **Проблема:** Початковий вимірювальний цикл використовував окремі corrected values без міжвимірювального згладжування, тому шум кожного каналу безпосередньо передавався у ratio.
- **Rev.1 Fix:** Реалізовано moving average з вікном `N = 8` окремо для `channel_1_corrected_raw` та `channel_2_corrected_raw`.
- **Архітектура:** Ratio не усереднюється напряму. Спочатку фільтруються два канали, після чого `filtered_ratio` розраховується із фільтрованих значень.
- **Rev.1.1:** Розмір вікна та тип фільтра визначити після експериментального аналізу шуму та необхідної швидкодії фотометра.

---

### Стан moving average не скидається при зміні dark calibration

- **Проблема:** Поточний moving average зберігає попередній буфер і накопичені суми незалежно від зміни dark offsets.
- **Наслідок:** Якщо dark calibration повторно виконується під час роботи, перші наступні filtered values міститимуть суміш результатів, скоригованих відносно старого та нового dark offset.
- **Поточний стан:** Для MVP проблема не проявляється у штатному режимі, оскільки dark calibration виконується один раз перед серією вимірювань.
- **Rev.1.1 / Firmware Fix:** Реалізувати reset moving-average buffer при встановленні нових dark offsets або після успішного `photometer_calibrate_dark()`.

---

## 4. Формат та логування вимірювань

### Початковий CSV не містив результатів цифрової фільтрації

- **Проблема:** Після додавання moving average структура вимірювання містила filtered values, але початковий output layer продовжував виводити лише raw/corrected data та ratio.
- **Rev.1 Fix:** CSV розширено полями:
  - `ch1_filtered`;
  - `ch1_filtered_uv`;
  - `ch2_filtered`;
  - `ch2_filtered_uv`;
  - `filtered_ratio`;
  - `filtered_ratio_valid`.
- **Rev.1.1:** Зберегти одночасний вивід raw, corrected та filtered data для можливості подальшої валідації алгоритмів обробки.

---

## 5. Пункти, що потребують перевірки перед фіналізацією ERRATA

- Перевірити, чи реалізована функція `photometer_clear_dark_offsets()`, оголошена у `photometer.h`. Якщо декларація існує без реалізації, або реалізувати функцію, або видалити невикористаний API.
- Перевірити необхідність внутрішніх `GPIO_PULLUP`, які застосовувалися під час bring-up. Не вважати їх постійним firmware workaround, якщо вони використовувалися лише як діагностичний захід.
- Після встановлення справного ADS1220/ADS1120 повторно перевірити, які SPI workaround залишаються необхідними на фізично справному цифровому інтерфейсі.

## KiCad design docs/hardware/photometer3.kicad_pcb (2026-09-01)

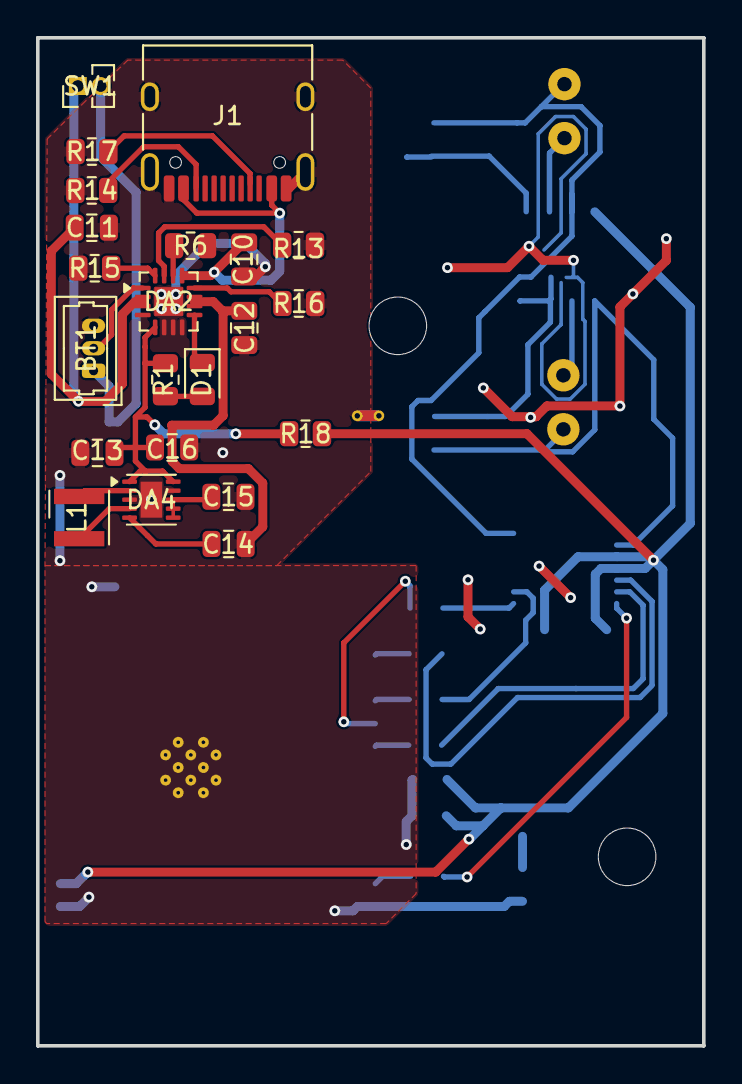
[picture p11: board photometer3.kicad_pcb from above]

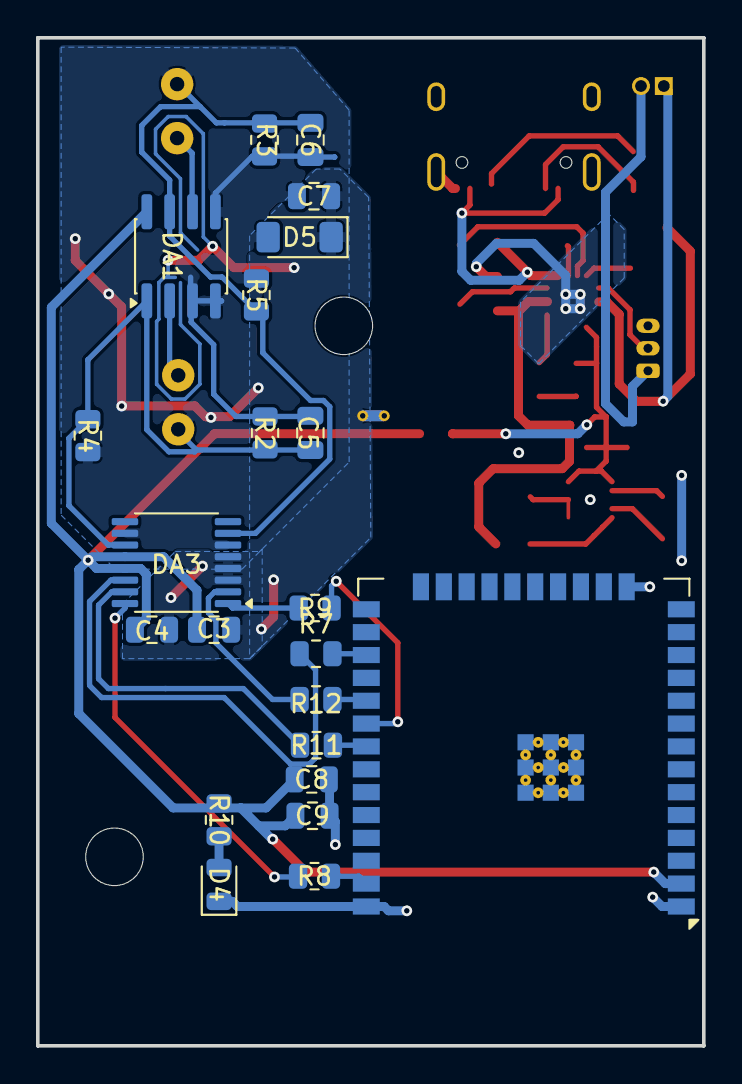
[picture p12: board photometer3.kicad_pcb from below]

Board: 2 copper layers, 37.0 x 56.0 mm, 49 parts (24 on the bottom side), 29 nets.

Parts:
BT1: Akyga LP603450 PCM+NTC; Molex_PicoBlade_53047-0310_1x03_P1.25mm_Vertical
C3, C4, C8: 100nF; C_0805_2012Metric
C5, C6: 10nF; C_0805_2012Metric
C7: 220nF; C_0805_2012Metric
C9, C10, C13, C14, C16: 10mcF; C_0805_2012Metric
C11, C12: 4,7mcF; C_0805_2012Metric
C15: 100mcF; C_0805_2012Metric
D1: LED Red, 0805; LED_0805_2012Metric
D2, D3: BPW21R; Hamamatsu_S1087_THT2
D4: LED Green, 0805; LED_0805_2012Metric
D5: BAS85; D_MiniMELF
DA1: AD8616ARZ; SOIC-8_3.9x4.9mm_P1.27mm
DA2: BQ24074RGT; VQFN-16-1EP_3x3mm_P0.5mm_EP1.6x1.6mm
DA3: ADS1220xPW; TSSOP-16_4.4x5mm_P0.65mm
DA4: TPS63031DSK; WSON-10-1EP_2.5x2.5mm_P0.5mm_EP1.2x2mm
DA5: ESP32-WROOM-32E
H1, H2: MountingHole; MountingHole_3.2mm_M3
J1: USB_C_Receptacle_USB2.0_16P; USB_C_Receptacle_HRO_TYPE-C-31-M-12
L1: 1.5uH; L_Wurth_WE-LQSH-3012
NT1: NetTie_2; NetTie-2_THT_Pad0.3mm
R1, R10: 1kR; R_0805_2012Metric
R2, R3: 5,1MR; R_0805_2012Metric
R4, R5: 22kR; R_0805_2012Metric
R6: 46,4kR; R_0805_2012Metric
R7, R8, R9, R11, R12: 47R; R_0805_2012Metric
R13: 4,12kR; R_0805_2012Metric
R14, R17: 5,1kR; R_0805_2012Metric
R15: 1,8kR; R_0805_2012Metric
R16: 1,6kR; R_0805_2012Metric
R18: 0R; R_0805_2012Metric
SW1: SW_Push; PinHeader_1x02_P1.27mm_Vertical

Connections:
/5V: C10.2, C12.1, C14.2, DA2.10 (OUT), DA2.11 (OUT), DA2.13 (IN), DA4.5 (VIN), J1.A4 (VBUS), J1.A9 (VBUS), J1.B4 (VBUS), J1.B9 (VBUS)
/+3V3: C3.1, C4.2, C8.2, C9.2, C13.1, C16.1, DA1.8 (V+), DA2.5 (EN2), DA3.12 (AVDD), DA3.13 (DVDD), DA4.1 (VOUT), DA4.10 (FB), DA5.2 (VDD), R1.2, R10.2, R18.1, R18.2
/AIN0: C5.1, DA1.1, DA3.11 (AIN0/REFP1), R2.1, R4.1
/AIN2: C6.1, DA1.7, DA3.7 (AIN2), R3.1, R5.1
/BAT: BT1.1 (+BAT), C11.1, DA2.2 (BAT), DA2.3 (BAT), SW1.1, SW1.2
/CS: DA3.2 (~CS), DA5.29 (IO5), R12.1, R12.2
/DIN: DA3.16 (DIN), DA5.37 (IO23), R8.1, R8.2
/DOUT: DA3.15 (DOUT/~DRDY), DA5.31 (IO19), R11.1, R11.2
/DRDY: DA3.14 (~DRDY), DA5.27 (IO16), R7.1, R7.2
/ILIM: DA2.12 (ILIM), R16.2
/ISET: DA2.16 (ISET), R15.2
/ITERM: DA2.15 (ITERM), R13.2
/L: DA4.4 (L1), L1.1
/NTC: BT1.2 (NTC), DA2.1 (TS)
/SCLK: DA3.1 (SCLK), DA5.30 (IO18), R9.1, R9.2
/VINA: C15.1, DA4.6 (EN), DA4.7 (PS/SYNC), DA4.8 (VINA)
/VSHIFT: C7.1, D2.2 (A), D3.2 (A), D5.2 (A), DA1.3 (+), DA1.4 (V-), DA1.5 (+), DA3.6 (AIN3/REFN1), DA3.10 (AIN1), R4.2, R5.2
GND: BT1.3 (GND), C8.1, C9.1, C10.1, C11.2, C12.2, C13.2, C14.1, C15.2, C16.2, D4.1 (K), DA2.0.3, DA2.6 (EN1), DA2.7 (~PGOOD), DA2.8 (VSS), DA2.17 (VSS), DA4.3 (PGND), DA4.9 (GND), DA4.11 (PGND), DA5.1 (GND), DA5.15 (GND), DA5.38 (GND), DA5.39 (GND), J1.A1 (GND), J1.A12 (GND), J1.B1 (GND), J1.B12 (GND), J1.SH (SHIELD), NT1.2, R6.1, R13.1, R14.1, R15.1, R16.1, R17.2
GNDA: C3.2, C4.1, C7.2, D5.1 (K), DA3.3 (CLK), DA3.4 (DGND), DA3.5 (AVSS), NT1.1
unnamed: D1.2 (A), R1.1
unnamed: D1.1 (K), DA2.9 (~CHG)
unnamed: C5.2, D2.1 (K), DA1.2 (-), R2.2
unnamed: D3.1 (K), R3.2
unnamed: D4.2 (A), R10.1
unnamed: C6.2, DA1.6 (-)
unnamed: DA2.14 (TMR), R6.2
unnamed: DA4.2 (L2), L1.2
unnamed: J1.A5 (CC1), R17.1
unnamed: J1.B5 (CC2), R14.2

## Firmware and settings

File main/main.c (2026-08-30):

#include <stdbool.h>
#include <stdio.h>
#include <stdint.h>

#include "esp_err.h"
#include "esp_timer.h"
#include "freertos/FreeRTOS.h"
#include "freertos/task.h"

#include "ads1220.h"
#include "photometer.h"
#include "photometer_output.h"

void app_main(void)
{
    esp_err_t result;

    result = ads1220_init();
    if (result != ESP_OK) {
        printf("ADS1220 init failed: %s\n", esp_err_to_name(result));
        return;
    }

    const uint8_t register_values[4] = {
        (uint8_t)(((uint8_t)ADS1220_INPUT_AIN0_AIN1 << 4) | ADS1220_REG0_GAIN_1 | ADS1220_REG0_PGA_ENABLED),
        (uint8_t)(ADS1220_REG1_DATA_RATE_20_SPS | ADS1220_REG1_NORMAL_MODE | ADS1220_REG1_SINGLE_SHOT | ADS1220_REG1_TEMPERATURE_SENSOR_DISABLED | ADS1220_REG1_BURNOUT_SOURCES_DISABLED),
        (uint8_t)(ADS1220_REG2_INTERNAL_REFERENCE | ADS1220_REG2_FILTER_50_60_HZ | ADS1220_REG2_LOW_SIDE_SWITCH_OPEN | ADS1220_REG2_IDAC_DISABLED),
        (uint8_t)(ADS1220_REG3_IDAC_ROUTING_DISABLED)
    };

    result = ads1220_configure(register_values);
    if (result != ESP_OK) {
        printf("ADS1220 configure failed: %s\n", esp_err_to_name(result));
        return;
    }

    result = photometer_light_init();
    if (result != ESP_OK) {
        printf("Light init failed: %s\n", esp_err_to_name(result));
        return;
    }

    const uint32_t sample_count = 4;
    const uint32_t timeout_ms = 200;
    uint32_t measurement_number = 0;

    photometer_output_print_csv_header();

    while (1) {
        int32_t channel_1_dark_offset_raw = 0;
        int32_t channel_2_dark_offset_raw = 0;

        result = photometer_light_off();
        if (result != ESP_OK) {
            printf("Light off failed: %s\n", esp_err_to_name(result));
            vTaskDelay(pdMS_TO_TICKS(500));
            continue;
        }

        vTaskDelay(pdMS_TO_TICKS(250));

        result = photometer_calibrate_dark(sample_count, timeout_ms, &channel_1_dark_offset_raw, &channel_2_dark_offset_raw);
        if (result != ESP_OK) {
            printf("Dark calibration failed: %s\n", esp_err_to_name(result));
            vTaskDelay(pdMS_TO_TICKS(500));
            continue;
        }

        result = photometer_light_on();
        if (result != ESP_OK) {
            printf("Light on failed: %s\n", esp_err_to_name(result));
            vTaskDelay(pdMS_TO_TICKS(500));
            continue;
        }

        vTaskDelay(pdMS_TO_TICKS(250));

        photometer_measurement_t measurement = {0};
        result = photometer_measure(sample_count, timeout_ms, &measurement);

        esp_err_t light_off_result = photometer_light_off();
        if (light_off_result != ESP_OK) {
            printf("Light off failed: %s\n", esp_err_to_name(light_off_result));
            return;
        }

        if (result != ESP_OK) {
            printf("Measurement failed: %s\n", esp_err_to_name(result));
            vTaskDelay(pdMS_TO_TICKS(500));
            continue;
        }

        measurement_number++;
        const int64_t timestamp_us = esp_timer_get_time();

        photometer_output_print_csv_measurement(
            timestamp_us,
            measurement_number,
            channel_1_dark_offset_raw,
            channel_2_dark_offset_raw,
            &measurement
        );

        vTaskDelay(pdMS_TO_TICKS(100));
    }
}

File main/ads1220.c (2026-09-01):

#include <stddef.h>
#include <stdint.h>
#include <stdio.h>
#include <stdbool.h>

#include "ads1220.h"
#include "driver/gpio.h"
#include "esp_rom_sys.h"
#include "esp_timer.h"
#include "freertos/FreeRTOS.h"
#include "freertos/task.h"

#define ADS1220_CMD_RDATA               0x10
#define ADS1220_CMD_POWERDOWN           0x02
#define ADS1220_CMD_RESET               0x06
#define ADS1220_CMD_RREG                0x20
#define ADS1220_CMD_START_SYNC          0x08
#define ADS1220_CMD_WREG                0x40

#define ADS1220_REGISTER_COUNT          4
#define ADS1220_REGISTER_0              0
#define ADS1220_REG0_NON_MUX_MASK       0x0F
#define ADS1220_REG0_MUX_SHIFT          4

#define ADS1220_CS_GPIO                 5
#define ADS1220_DRDY_GPIO               16
#define ADS1220_SCLK_GPIO               18
#define ADS1220_MISO_GPIO               19
#define ADS1220_MOSI_GPIO               23

#define ADS1220_RESET_DELAY_US          200
#define ADS1220_READY_POLL_DELAY_US     100

#define ADS1220_INTERNAL_REFERENCE_UV   2048000.0
#define ADS1220_FULL_SCALE_COUNTS       8388608.0
#define ADS1220_CONFIGURED_GAIN         1.0

#define ADS1220_RAW_POSITIVE_FULL_SCALE 8388607
#define ADS1220_RAW_NEGATIVE_FULL_SCALE (-8388608)

static uint8_t ads1220_bitbang_transfer_byte(uint8_t tx_byte)
{
    uint8_t rx_byte = 0;
    for (int bit = 7; bit >= 0; bit--) {
        gpio_set_level(ADS1220_MOSI_GPIO, (tx_byte >> bit) & 0x01);
        esp_rom_delay_us(30);
        gpio_set_level(ADS1220_SCLK_GPIO, 1);
        esp_rom_delay_us(30);
        gpio_set_level(ADS1220_SCLK_GPIO, 0);

        if (gpio_get_level(ADS1220_MISO_GPIO)) {
            rx_byte |= (uint8_t)(1U << bit);
        }
        esp_rom_delay_us(30);
    }
    return rx_byte;
}

static esp_err_t ads1220_wait_drdy(uint32_t timeout_ms)
{
    const int64_t start_us = esp_timer_get_time();
    const int64_t timeout_us = (int64_t)timeout_ms * 1000;

    while (gpio_get_level(ADS1220_DRDY_GPIO) == 0) {
        if ((esp_timer_get_time() - start_us) > timeout_us) {
            return ESP_ERR_TIMEOUT;
        }
        esp_rom_delay_us(10);
    }

    while (gpio_get_level(ADS1220_DRDY_GPIO) != 0) {
        if ((esp_timer_get_time() - start_us) > timeout_us) {
            return ESP_ERR_TIMEOUT;
        }
        esp_rom_delay_us(50);
    }

    return ESP_OK;
}

static esp_err_t ads1220_send_command(uint8_t command)
{
    gpio_set_level(ADS1220_CS_GPIO, 0);
    esp_rom_delay_us(10);
    ads1220_bitbang_transfer_byte(command);
    esp_rom_delay_us(10);
    gpio_set_level(ADS1220_CS_GPIO, 1);
    return ESP_OK;
}

esp_err_t ads1220_start_conversion(void)
{
    return ads1220_send_command(ADS1220_CMD_START_SYNC);
}

esp_err_t ads1220_power_down(void)
{
    return ads1220_send_command(ADS1220_CMD_POWERDOWN);
}

esp_err_t ads1220_reset(void)
{
    esp_err_t result = ads1220_send_command(ADS1220_CMD_RESET);
    if (result != ESP_OK) {
        return result;
    }
    esp_rom_delay_us(ADS1220_RESET_DELAY_US);
    return ESP_OK;
}

esp_err_t ads1220_recover(const uint8_t register_values[4])
{
    if (register_values == NULL) {
        return ESP_ERR_INVALID_ARG;
    }
    esp_err_t result = ads1220_reset();
    if (result != ESP_OK) {
        return result;
    }
    return ads1220_configure(register_values);
}

esp_err_t ads1220_wait_ready(uint32_t timeout_ms)
{
    const int64_t start_time_us = esp_timer_get_time();
    const int64_t timeout_us = (int64_t)timeout_ms * 1000;

    while (1) {
        if (gpio_get_level(ADS1220_DRDY_GPIO) == 0) {
            return ESP_OK;
        }
        if ((esp_timer_get_time() - start_time_us) >= timeout_us) {
            return ESP_ERR_TIMEOUT;
        }
        esp_rom_delay_us(ADS1220_READY_POLL_DELAY_US);
    }
}

esp_err_t ads1220_read_register(uint8_t register_address, uint8_t *register_value)
{
    if (register_value == NULL || register_address >= ADS1220_REGISTER_COUNT) {
        return ESP_ERR_INVALID_ARG;
    }

    const uint8_t command = (uint8_t)(ADS1220_CMD_RREG | (register_address << 2));

    gpio_set_level(ADS1220_CS_GPIO, 0);
    esp_rom_delay_us(10);
    ads1220_bitbang_transfer_byte(command);
    *register_value = ads1220_bitbang_transfer_byte(0x00);
    esp_rom_delay_us(10);
    gpio_set_level(ADS1220_CS_GPIO, 1);

    return ESP_OK;
}

esp_err_t ads1220_write_register(uint8_t register_address, uint8_t register_value)
{
    if (register_address >= ADS1220_REGISTER_COUNT) {
        return ESP_ERR_INVALID_ARG;
    }

    const uint8_t command = (uint8_t)(ADS1220_CMD_WREG | (register_address << 2));

    gpio_set_level(ADS1220_CS_GPIO, 0);
    esp_rom_delay_us(10);
    ads1220_bitbang_transfer_byte(command);
    ads1220_bitbang_transfer_byte(register_value);
    esp_rom_delay_us(10);
    gpio_set_level(ADS1220_CS_GPIO, 1);

    return ESP_OK;
}

esp_err_t ads1220_select_input(ads1220_input_t input)
{
    if (input != ADS1220_INPUT_AIN0_AIN1 && input != ADS1220_INPUT_AIN2_AIN3) {
        return ESP_ERR_INVALID_ARG;
    }

    uint8_t reg_val = 0;
    esp_err_t result = ads1220_read_register(ADS1220_REGISTER_0, &reg_val);
    if (result != ESP_OK) {
        return result;
    }

    reg_val = (uint8_t)((reg_val & ADS1220_REG0_NON_MUX_MASK) | ((uint8_t)input << ADS1220_REG0_MUX_SHIFT));
    result = ads1220_write_register(ADS1220_REGISTER_0, reg_val);
    if (result != ESP_OK) {
        return result;
    }

    uint8_t readback_val = 0;
    result = ads1220_read_register(ADS1220_REGISTER_0, &readback_val);
    if (result != ESP_OK) {
        return result;
    }
    if (readback_val != reg_val) {
        return ESP_ERR_INVALID_RESPONSE;
    }

    return ESP_OK;
}
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

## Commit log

2026-08-30 Add project overview and technical specifications to README
    Added detailed project description, hardware specifications, firmware details, measurement pipeline, current status, known limitations, and next steps.
2026-08-30 Enhance README with PCB visuals and schematics
    Added 3D renderings, PCB layout, and schematics sections to README.
2026-08-30 docs: add hardware renders, schematics and update readme
2026-08-30 Revise README to enhance hardware and prototype details
    Updated hardware section with core components and added images for the physical prototype, 3D visualization, PCB layout, and schematic.
2026-09-01 docs: add hardware errata
    [ads1220.c]
2026-09-01 docs: add hardware and firmware errata, bring-up logs, rearrange README.md
    [bring-up_logs.csv]
2026-09-01 docs: add pcb pro. and the rest of the files, also added BOM
    [photometer.BOM.xlsx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]
2026-09-04 docs: add replacement for the .sch and pro. files
    [photometer3.kicad_sch]
